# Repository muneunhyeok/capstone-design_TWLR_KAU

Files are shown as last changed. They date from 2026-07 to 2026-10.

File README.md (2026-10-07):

# TWLR — 2륜 밸런싱 로봇 (한국항공대 캡스톤디자인)

<table>
<tr>
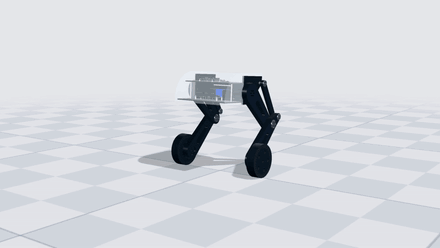
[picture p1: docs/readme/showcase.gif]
TWLR 모션 쇼케이스
<td width="50%" align="center"></td>
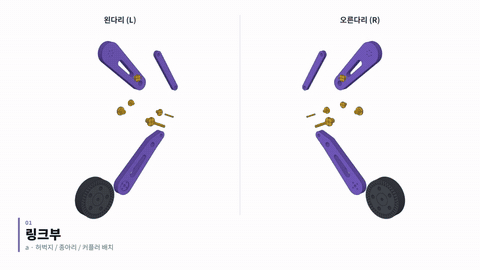
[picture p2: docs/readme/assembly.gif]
TWLR 어셈블리
<td width="50%" align="center"></td>
</tr>
<tr>
<td align="center"><b>모션 쇼케이스</b> — SQUAT · ROLL · DRIVE · TURN<br><sub>서보 축 높이 340–510 mm · 좌우 독립 롤 · 도립진자 밸런싱 주행 · 선회 시 기울기 보정</sub><br><a href="hardware/media/motion-showcase.mp4">▶ 원본 영상 (42 s)</a></td>
<td align="center"><b>어셈블리</b> — 링크부 → 토르소부 → 링크부 + 몸체<br><sub>좌우 4절 링크 다리 · 상·하판 서브어셈블리 · 커플러 부시 샤프트 체결</sub><br><a href="hardware/media/assembly-animation-v2.mp4">▶ 원본 영상 (36 s)</a></td>
</tr>
</table>

<sub>GIF 는 1.5~2 배속 미리보기입니다. 클릭하면 원본 mp4 로 이동합니다.</sub>

> **최근 변경 (2026-10)** — 고관절 액추에이터를 CubeMars AK45-36 → **Damiao DM-J4340P-2EC** 로 교체 (AK45 배송 지연).
> 토크 해석 재계산, 구매 BOM, 2·3주차 발표자료, 모션 쇼케이스·어셈블리 v2 영상 추가.

이 저장소는 두 부분으로 나뉩니다.

| | 내용 | 진입점 |
|---|---|---|
| **기구 설계 (CAD)** | CATIA, Fusion 360 어셈블리, 3D 프린팅 STL, 구조·정역학 해석 | **[`hardware/`](hardware/)** |
| **ROS 2 description** | URDF/xacro, 메시, RViz·robot_state_publisher 런치 | [`urdf/`](urdf/) · 아래 섹션 |

## 기구 설계 요약 → [`hardware/README.md`](hardware/README.md)

| | |
|---|---|
| Fusion 문서 | `TWLR_assembly_AK45` (컴포넌트 31 / 오컬런스 55 / 타임라인 281) — 고관절 인터페이스는 아직 AK45 기준 |
| 총질량 | **11.24 kg** (PLA 벽 6줄 / 인필 20 %, DM4340P 반영) |
| 무게중심 | 지면 위 **271.5 mm**, 휠축 위 **185.5 mm**, 좌우 대칭 X = 0.000 mm |
| 고관절 | Damiao **DM-J4340P-2EC** × 2 (40:1, CAN) — 직립 시 필요토크 **9.59 N·m** (정격 9 의 107 %, 피크 27 의 36 %) |
| 휠 | **WA172E** 인휠모터 Ø172 × 2 (4-M6 PCD36 체결) |
| 다리 | 좌우 **4절 링크**, 기구학 한계 Δθ = −27.1° … +36.1° · 팀 권장 운용범위 −20.9° … +21.6° (3주차) |
| 전장 | LattePanda (상위) · Teensy 4.1 (하위) · BNO085 IMU · CAN 트랜시버 · ODrive (휠) |

**영상**: [모션 쇼케이스 — SQUAT · ROLL · DRIVE · TURN](hardware/media/motion-showcase.mp4) (42 s) ·
[어셈블리 v2](hardware/media/assembly-animation-v2.mp4) (36 s) ·
[토르소 출력 시뮬레이션](hardware/media/torso-print-sim-cura.mp4) ·
[어셈블리 v1](hardware/media/assembly-animation.mp4) (27 s)

상세 문서: [01 고관절 AK45 (이전안)](docs/mechanical/01-hip-actuator-AK45.md) ·
[02 조인트/부시/샤프트](docs/mechanical/02-joints-bushings-shafts.md) ·
[03 질량·무게중심·힙토크](docs/mechanical/03-mass-cog-hip-torque.md) ·
[04 3D프린팅 방향·인필](docs/mechanical/04-print-orientation-infill.md) ·
[**05 고관절 DM4340P 변경**](docs/mechanical/05-hip-actuator-DM4340P.md) ·
[구매 BOM](hardware/bom/)

**발표자료 (2026-2학기)**

| 주차 | 발표일 | 제목 | 주요 내용 |
|---|---|---|---|
| [1주차](docs/presentations/2026-2-week1/) | 09-07 | 하드웨어 제작·설계 및 시뮬레이션 결과 보고 | Simulink, 부시·샤프트, 모터 구동 |
| [2주차](docs/presentations/2026-2-week2/) | 09-14 | 하드웨어 제작 및 시뮬레이션 결과 보고 | Simulink(CoM·피치), 모션 시뮬레이션, 부시 최소길이, 링크 3D 프린팅, 모듈 구동 |
| [3주차](docs/presentations/2026-2-week3/) | 09-21 | 하드웨어 제작 및 센서 구동 테스트 | 구동각 제한(조립·간섭·전달각), 정역학·동역학, LattePanda 휠 구동, BNO085 IMU |

---

# ROS 2 Robot Description

> ⚠️ **아래 URDF 는 구버전 Fusion 모델에서 자동생성된 것입니다.**
> 질량 63.541 kg, 링크명 `link1`/`link3` 등은 현재 CAD(`TWLR_assembly_AK45`, DM4340P 반영 11.24 kg)와 맞지 않습니다.
> 기구가 확정되었으므로 URDF 재생성이 필요합니다 — 실제 질량·관성값은
> [`hardware/analysis/results/mass-and-cog.txt`](hardware/analysis/results/mass-and-cog.txt) 참고.

## Overview (구버전 자동생성값)

| Property | Value |
|---|---|
| Total mass | 63.541 kg *(실제 11.24 kg)* |
| Links | 7 |
| Joints | 6 (6 movable) |
| Assemblies | 14 |
| Root link | `base_link` |

## Table of Contents

- [Kinematic Tree](#kinematic-tree)
- [Link Properties](#link-properties)
- [Joint Properties](#joint-properties)
- [Assembly Breakdown](#assembly-breakdown)
- [Quick Start (ROS 2)](#quick-start-ros-2)
- [Files](#files)

## Kinematic Tree

```
base_link
  └─ hip_right [continuous]
    link1_right [BAKE]
      └─ knee_right [continuous]
        link3_right [BAKE]
          └─ wheel_right [continuous]
            wheel_right [BAKE]
      └─ hip_left [continuous]
        link1_left [BAKE]
          └─ knee_left [continuous]
            link3_left [BAKE]
              └─ wheel_left [continuous]
                wheel_left [BAKE]
```

## Link Properties

| Link | Mass (kg) | Material | Collision | Bodies |
|---|---|---|---|---|
| `base_link` | 46.8047 | material | cylinder | 1 |
| `link1_left` | 0.6681 | material | box | 1 |
| `link1_right` | 0.6681 | material | box | 1 |
| `link3_left` | 0.8086 | material | cylinder | 1 |
| `link3_right` | 0.8086 | material | cylinder | 1 |
| `wheel_left` | 6.8914 | material | box | 2 |
| `wheel_right` | 6.8914 | material | box | 2 |

## Joint Properties

| Joint | Type | Parent → Child | Axis | Limits |
|---|---|---|---|---|
| `hip_left` | continuous | `link1_right` → `link1_left` | (1,0,0) | — |
| `hip_right` | continuous | `base_link` → `link1_right` | (1,0,0) | — |
| `knee_left` | continuous | `link1_left` → `link3_left` | (1,0,0) | — |
| `knee_right` | continuous | `link1_right` → `link3_right` | (1,0,0) | — |
| `wheel_left` | continuous | `link3_left` → `wheel_left` | (-0,0,-1) | — |
| `wheel_right` | continuous | `link3_right` → `wheel_right` | (0,-0,-1) | — |

## Assembly Breakdown

> 아래는 구버전 자동생성 목록이 아니라, 실제 Fusion 360 모델(`TWLR_assembly_AK45`,
> [`hardware/cad/TWLR_assembly_AK45.f3d`](hardware/cad/TWLR_assembly_AK45.f3d))에서 측정한 질량 특성입니다.
> PLA 부품은 **벽 6줄(2.4 mm) + 인필 20 %** 셸 모델 기준
> (`f = (V_shell + infill·(V−V_shell)) / V`), 구매품(DM4340P·WA172E·배터리 등)은 데이터시트/실측값.
> 고관절 액추에이터는 **DM4340P 375 g** 으로 갱신 (형상·중심은 CAD 의 AK45 자리값 사용 — 외형 Ø57 vs Ø55, 길이 동일).
> 좌표는 **고관절 축 원점** 기준 mm (X 좌우, Y 전후, Z 상하).
> 재현: [`hardware/analysis/mass_cog.py`](hardware/analysis/mass_cog.py) ·
> 원본 출력: [`hardware/analysis/results/mass-and-cog.txt`](hardware/analysis/results/mass-and-cog.txt)

### BODY — 토르소 · 배터리 · 전장 · 고관절 액추에이터 (4.615 kg)

| 부품 | 체적 [cm³] | 재료 | 유효충전율 | 질량 [g] | 중심 (X, Y, Z) mm |
|---|---:|---|---:|---:|---|
| Part12 토르소 메인 | 1486.1 | PLA | 65.4% | 1204.4 | (0.0, 47.9, −1.4) |
| Part14 외장/프레임 | 1040.8 | PLA | 88.2% | 1138.5 | (0.0, −81.4, 43.4) |
| Part13 배터리 (6S LiPo) | 301.9 | BATT | 실측 | 700.0 | (0.0, 0.0, −7.7) |
| Part16 하부 패널 | 282.3 | PLA | 100.0% | 350.0 | (0.0, −74.0, −46.2) |
| 20_ACT DM4340P L | 132.9 | DM4340P | 데이터시트 | 375.0 | (−111.9, −0.1, 0.0) |
| 20_ACT DM4340P R | 132.9 | DM4340P | 데이터시트 | 375.0 | (111.9, 0.1, 0.0) |
| Part15 상부 패널 | 260.9 | PLA | 100.0% | 323.6 | (0.0, −22.0, 46.2) |
| Driver PCB v3.5 | 34.5 | PCB | 100% | 65.5 | (−3.1, −124.8, −28.4) |
| PCB | 8.5 | PCB | 100% | 16.1 | (−0.3, −66.4, 50.3) |
| Carte PCB | 1.6 | PCB | 100% | 3.1 | (60.3, 0.2, 49.0) |

### THIGH — 허벅지 링크 · 출력 허브 · 베어링 (1.149 kg, 좌우 대칭)

| 부품 | 체적 [cm³] | 재료 | 유효충전율 | 질량 [g] | 중심 (X, Y, Z) mm |
|---|---:|---|---:|---:|---|
| 06_Thigh_L | 604.8 | PLA | 45.7% | 342.5 | (−187.1, 73.6, −69.3) |
| 08_Thigh_R | 604.8 | PLA | 45.7% | 342.5 | (187.1, 73.6, −69.3) |
| 21_HUB L (출력 허브) | 49.1 | AL6061 | 100% | 132.4 | (−162.8, 0.0, 0.0) |
| 21_HUB R | 49.1 | AL6061 | 100% | 132.4 | (162.8, 0.0, 0.0) |
| 6905 베어링 ×4 (25×42×9) | 6.3 ea | STEEL | 100% | 49.8 ea | X = ∓177.5 / ∓186.5 |

### SHIN — 종아리 링크 · 인휠모터 · 베어링/부시 (5.300 kg, 좌우 대칭)

| 부품 | 체적 [cm³] | 재료 | 유효충전율 | 질량 [g] | 중심 (X, Y, Z) mm |
|---|---:|---|---:|---:|---|
| 10_Wheel_WA172E_L | 947.4 | WA172E | 실측 | 2200.0 | (−257.6, 4.0, −336.0) |
| 11_Wheel_WA172E_R | 947.4 | WA172E | 실측 | 2200.0 | (257.6, 4.0, −336.0) |
| 07_Shin_L | 577.9 | PLA | 50.8% | 364.4 | (−213.9, 106.7, −234.9) |
| 09_Shin_R | 577.9 | PLA | 50.8% | 364.4 | (213.9, 106.7, −234.9) |
| 6904 베어링 ×4 (20×37×9) | 5.4 ea | STEEL | 100% | 42.3 ea | X = ∓215.5 / ∓224.5, (Y,Z)=(174.0,−164.0) |
| bush @B (플랜지 부시) ×2 | 0.8 ea | iglidur | 100% | 1.2 ea | X = ∓165.0, (Y,Z)=(228.5,−128.6) |

### COUP — 보조링크 · 부시 (0.176 kg, 좌우 대칭)

| 부품 | 체적 [cm³] | 재료 | 유효충전율 | 질량 [g] | 중심 (X, Y, Z) mm |
|---|---:|---|---:|---:|---|
| 02_Coupler_L | 116.2 | PLA | 60.2% | 86.7 | (−162.0, 169.3, −36.7) |
| 03_Coupler_R | 116.2 | PLA | 60.2% | 86.7 | (162.0, 169.3, −36.7) |
| bush @A (플랜지 부시) ×2 | 0.8 ea | iglidur | 100% | 1.2 ea | X = ∓165.0, (Y,Z)=(114.0,49.0) |

### 전체 합계

| 항목 | 값 |
|---|---|
| 그룹 BODY | 4.615 kg |
| 그룹 THIGH | 1.149 kg |
| 그룹 SHIN | 5.300 kg |
| 그룹 COUP | 0.176 kg |
| **총질량** | **11.239 kg** (AK45 기준 11.187 kg) |
| **무게중심** | **(−0.0, 11.4, −150.5) mm** — 고관절 축 원점 기준 |
| 지면(휠 반경 86 mm) 기준 CoG 높이 | **271.5 mm** |

## Quick Start (ROS 2)

```bash
# 1. Copy package to your ROS 2 workspace
cp -r TWLR_description ~/ros2_ws/src/

# 2. Build
cd ~/ros2_ws
colcon build --packages-select TWLR_description
source install/setup.bash

# 3. Visualize in RViz2
ros2 launch TWLR_description display.launch.py

# 4. Validate URDF structure
check_urdf install/TWLR_description/share/TWLR_description/urdf/TWLR.urdf

# 5. Print kinematic tree
urdf_to_graphviz install/TWLR_description/share/TWLR_description/urdf/TWLR.urdf
```

**Joint control**: The launch file includes `joint_state_publisher_gui` —
use the sliders to move revolute/prismatic joints in RViz2.

**Topic inspection**:
```bash
# See published joint states
ros2 topic echo /joint_states

# See robot description parameter
ros2 param get /robot_state_publisher robot_description
```

## Files

| Path | Description |
|---|---|
| `urdf/TWLR.urdf.xacro` | Top-level xacro (entry point) |
| `urdf/TWLR.urdf` | Flat URDF (for validation) |
| `urdf/assemblies/` | Per-assembly xacro macros |
| `meshes/` | Visual (OBJ) and collision (STL) meshes |
| `launch/display.launch.py` | Launch robot_state_publisher, RViz, and generated controllers |
| `config/joint_state.yaml` | Joint state publisher config |
| `config/ros2_controllers.yaml` | Generated ros2_control controller manager config |
| `robot_data.yaml` | Supplementary data (beyond URDF) |
| `docs/transforms.md` | Transformation matrices (KaTeX) |
| `hardware/` | **기구 설계 — CAD, STL, 해석 (아래 표)** |
| `hardware/cad/TWLR_assembly_AK45.f3d` | Fusion 360 어셈블리 원본 |
| `hardware/cad/step/` | 신규 가공품 STEP (허브·마운트링·샤프트 3종) |
| `hardware/print/print-ready/` | 슬라이서용 STL — 구멍 없음 + 눕힘 + 베드 최적 회전 |
| `hardware/print/as-designed/` | 설계 그대로의 STL (구멍 포함) |
| `hardware/analysis/` | 질량·힙토크·볼트·프린팅 강도 해석 스크립트 + 결과 |
| `hardware/media/` | 어셈블리 애니메이션 v1·v2, 모션 쇼케이스, 토르소 출력 시뮬레이션 |
| `hardware/bom/` | 구매 BOM (xlsx + 요약) |
| `docs/mechanical/` | 기구 설계 상세 문서 5편 (05 = DM4340P 변경) |
| `firmware/` | Teensy 4.1 펌웨어 (BNO085 쿼터니언 송신) |
| `host/` | LattePanda/Ubuntu 측 코드 (IMU 수신·파싱, ODrive 휠 설정) |
| `docs/presentations/2026-2-week{1,2,3}/` | 2026-2학기 주차별 발표자료 (슬라이드·PDF·영상) |

## Customizing

Assemblies tagged `!dummy_` are designed to be swapped out. To replace one:

1. Create your replacement as a xacro macro with the same interface
2. Place it in `urdf/assemblies/`
3. Update the `<xacro:include>` in `urdf/TWLR.urdf.xacro`
4. Update meshes in `meshes/<your_assembly>/`

The xacro prefix system (`${prefix}`) ensures link names stay unique
when multiple instances of the same assembly are used.

---
*Generated by Fusion URDF/XACRO Exporter v3.0.0*

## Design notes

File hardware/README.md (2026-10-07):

# TWLR — 기구 설계 (Mechanical Design)

한국항공대학교 기계공학과 캡스톤디자인 · 2륜 밸런싱 로봇 **TWLR**

Fusion 360 문서: **`TWLR_assembly_AK45`** — 컴포넌트 31, 오컬런스 55, 타임라인 281, 스냅샷 7

> **2026-10 고관절 액추에이터 변경**: CubeMars AK45-36 → **Damiao DM-J4340P-2EC** (AK45 배송 지연).
> 해석값은 DM4340P 기준으로 갱신했고, CAD 의 허브/마운트링은 아직 AK45 기준입니다 → [05](../docs/mechanical/05-hip-actuator-DM4340P.md)

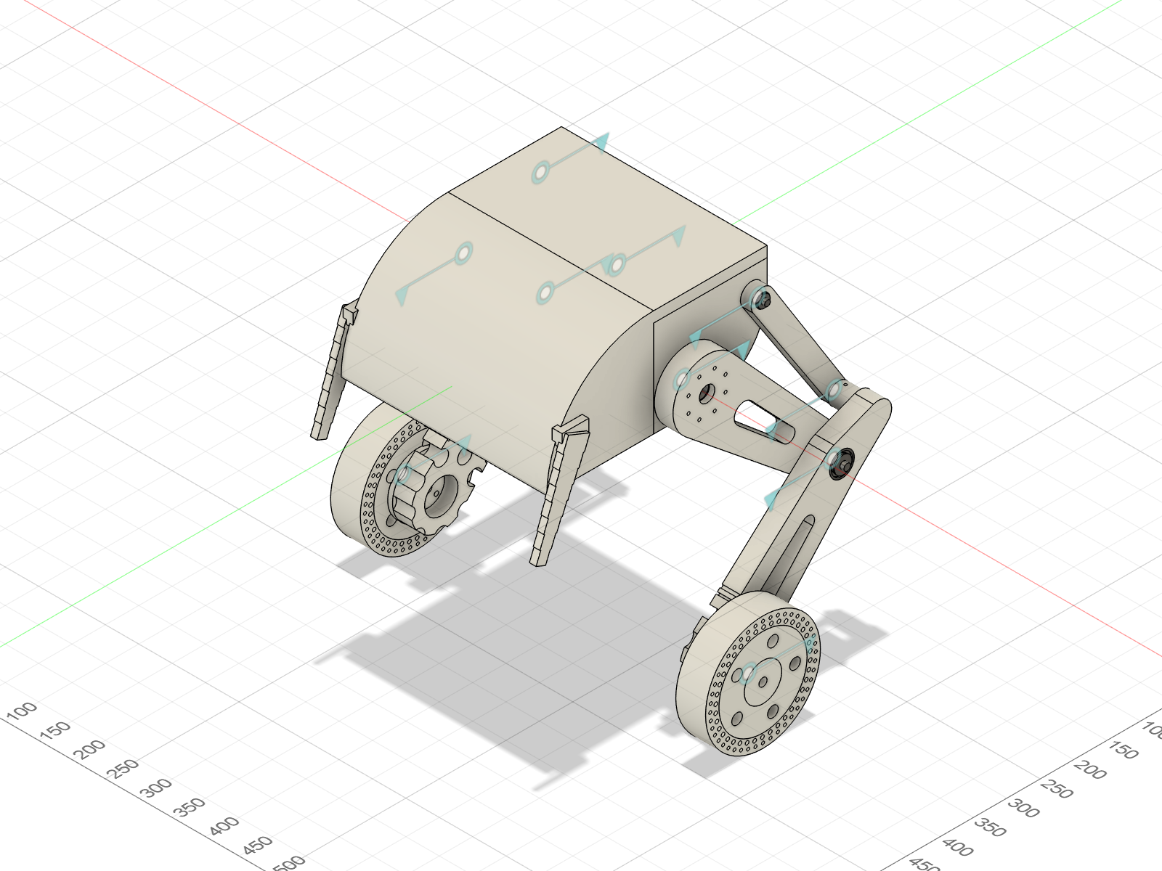
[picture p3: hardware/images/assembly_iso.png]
TWLR assembly


▶ **어셈블리 애니메이션 v2** (링크부 → 토르소부 → 결합, 36 s): [`media/assembly-animation-v2.mp4`](media/assembly-animation-v2.mp4)
· **모션 쇼케이스** (SQUAT · ROLL · DRIVE · TURN, 42 s): [`media/motion-showcase.mp4`](media/motion-showcase.mp4)
· 토르소 출력 시뮬레이션 (Cura): [`media/torso-print-sim-cura.mp4`](media/torso-print-sim-cura.mp4)
· v1 (27 s): [`media/assembly-animation.mp4`](media/assembly-animation.mp4)

발표자료: [1주차](../docs/presentations/2026-2-week1/) · [2주차](../docs/presentations/2026-2-week2/) · [3주차](../docs/presentations/2026-2-week3/)
· 구매 BOM: [`bom/`](bom/)

| | |
|---|---|
| 총질량 | **11.24 kg** (PLA 벽 6줄 / 인필 20 % 기준, DM4340P 반영) |
| 무게중심 | (0.0, +11.4, −150.5) mm — 지면에서 **271.5 mm**, 휠축 위 **185.5 mm** |
| 고관절 액추에이터 | Damiao **DM-J4340P-2EC** × 2 (40:1, 정격 9 N·m / 피크 27 N·m, CAN, 듀얼 엔코더) |
| 구동 휠 | **WA172E** 인휠모터 Ø172 × 2 |
| 다리 구조 | 좌우 **4절 링크** (허벅지 + 종아리 + 보조링크) |
| 좌우 대칭 | 무게중심 X = 0.000 mm |

<table>
<tr>
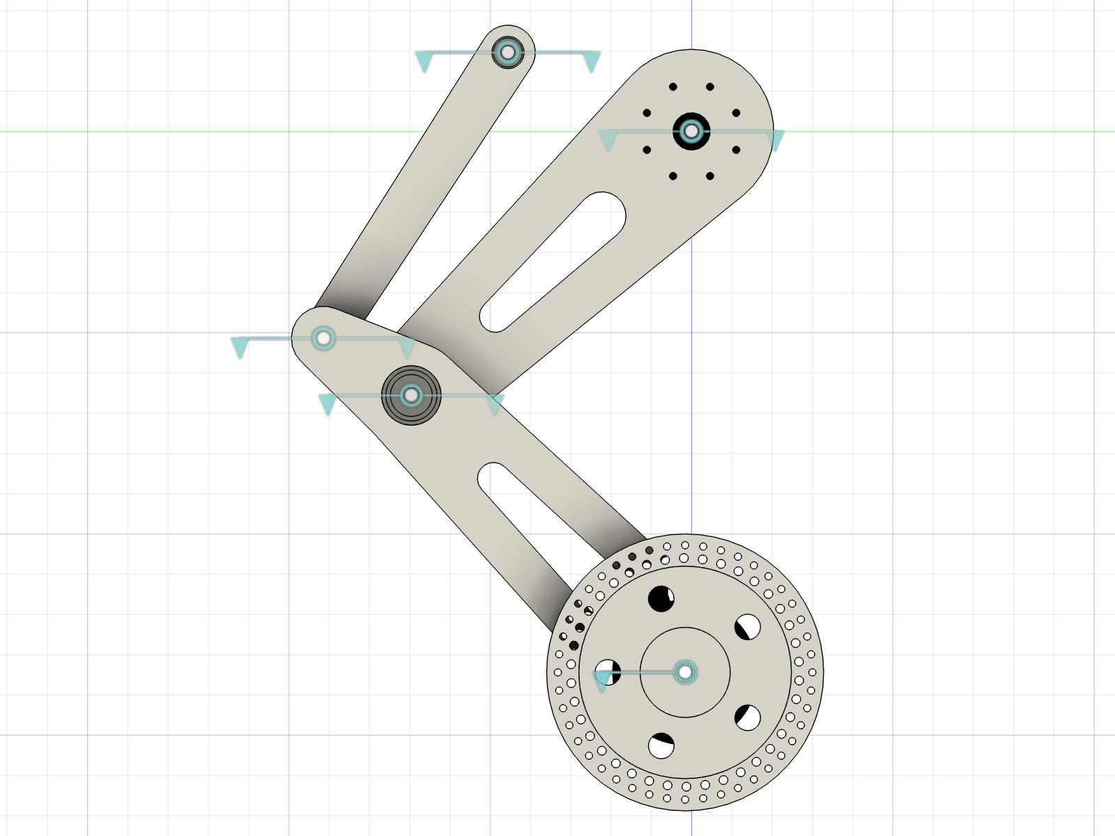
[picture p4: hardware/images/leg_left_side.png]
left leg
<td width="50%"></td>
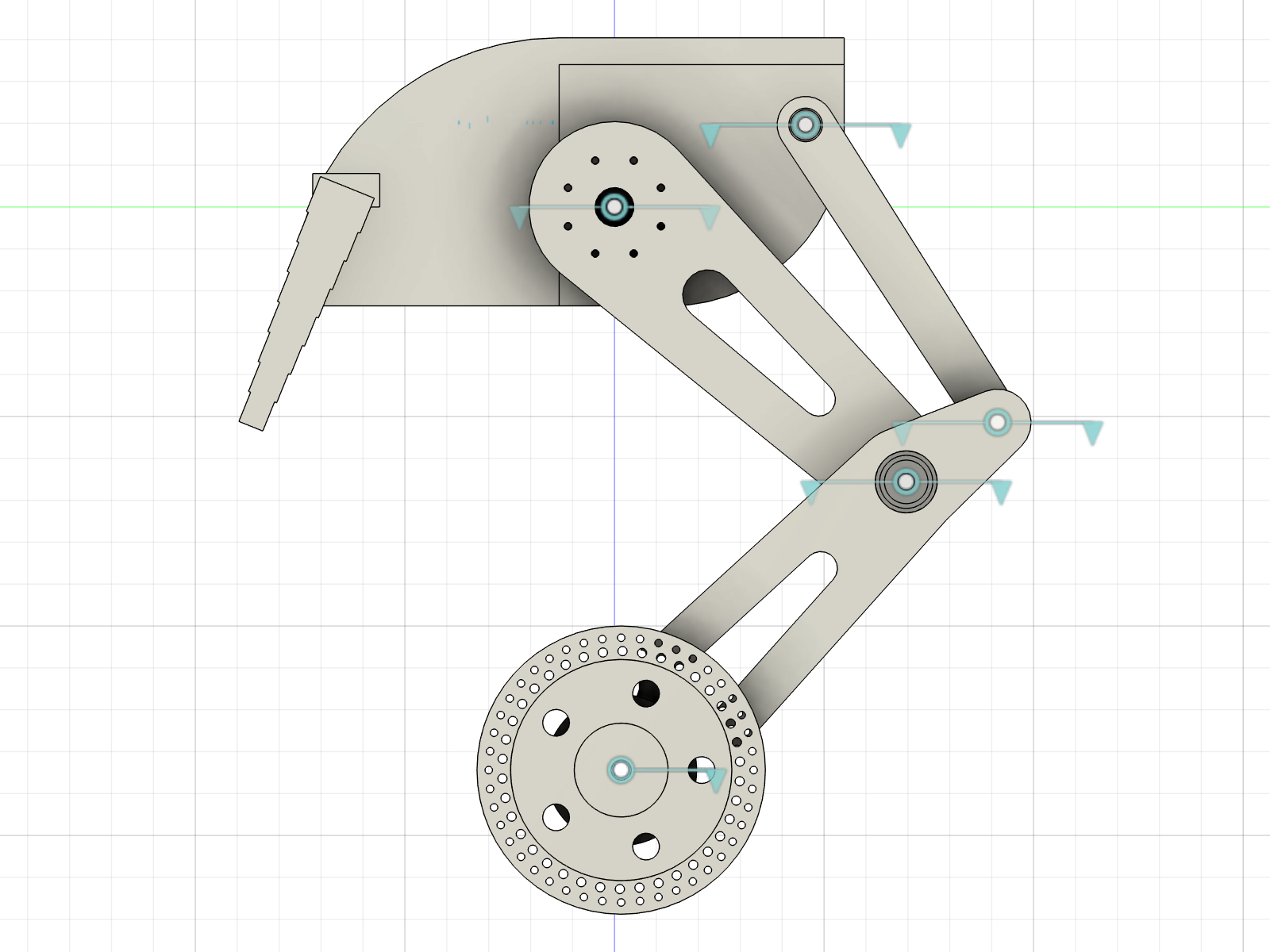
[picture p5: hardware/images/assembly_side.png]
side view
<td width="50%"></td>
</tr>
<tr><td align="center">좌측 다리 4절 링크</td><td align="center">측면</td></tr>
</table>

---

## 1. 좌표계

어셈블리 원점 = **좌우 고관절 축의 중점**

| 축 | 방향 |
|---|---|
| **X** | 좌우 (우측 +) |
| **Y** | 전후 |
| **Z** | 상하 (위 +) |

지면은 Z = −336 − 86 = **−422 mm** (휠 중심 Z = −336, 휠 반경 86).

## 2. 링크 구조 (4절 링크)

```
        고관절 (0, 0)                     A (114, 49)
             │  L1 = 239.1                     │
             │                                 │ L3 = 211.3
        무릎 (174, −164) ──── L2 = 65.0 ──── B (228.5, −128.6)
             │
             │ 241.8
        휠축 (4, −336)   ← Ø172 인휠모터
```

| 조인트 | 위치 (Y, Z) mm | 연결 | 베어링 / 부시 |
|---|---|---|---|
| **HIP** | (0, 0) | 토르소 ↔ 허벅지 | DM4340P 내장 크로스 롤러 베어링 |
| **A** | (114, 49) | 토르소 ↔ 보조링크 | 플랜지 부시 Ø12/Ø14 L15 |
| **KNEE** | (174, −164) | 허벅지 ↔ 종아리 | 6904ZZ × 2 |
| **B** | (228.5, −128.6) | 보조링크 ↔ 종아리 | 플랜지 부시 Ø12/Ø14 L15 |
| **WHEEL** | (4, −336) | 종아리 ↔ 휠 | 인휠모터 내장 |

고관절 각도 가동범위 Δθ = **−27.1° … +36.1°** (Grashof 조건 및 4절 폐쇄해 기준)

## 3. 부품 목록 (BOM)

### 3-1. 3D 프린팅 (PLA)

| 부품 | 수량 | 체적 | 외형 (T×Y×Z) |
|---|---|---|---|
| `06_Thigh_L` / `08_Thigh_R` 허벅지 | 2 | 604,281 mm³ | 28 × 258 × 248 |
| `07_Shin_L` / `09_Shin_R` 종아리 | 2 | 571,740 mm³ | 65 × 288.5 × 271.4 |
| `02_Coupler_L` / `03_Coupler_R` 보조링크 | 2 | 116,188 mm³ | 16 × 146.5 × 209.6 |
| `Part12` 토르소 메인 | 1 | 1,486,107 mm³ | 308 × 170 × 144 |
| `Part14` 외장 / `Part15` 상판 / `Part16` 하판 | 각 1 | 1,040,771 / 260,945 / 282,257 mm³ | — |

### 3-2. 신규 가공품 (알루미늄 / 강)

| 부품 | 수량 | 체적 | 재질 권고 | 기능 |
|---|---|---|---|---|
| `21_HUB_Hip_Output` | 2 | 49,052 mm³ | **A6061-T6** | 액추에이터 출력 → 허벅지(Ø70/PCD60) 어댑터 — **DM4340P 출력 플랜지에 맞춰 재설계 필요** |
| `22_MNT_AK45_Ring` | 2 | 11,738 mm³ | A6061-T6 | 액추에이터 하우징 ↔ 토르소 끝판 — **DM4340P 하우징 패턴에 맞춰 재설계 필요** |
| `40_SHAFT_A_D17-D12_L27` | 2 | 3,915 mm³ | S45C/SUS304 연마 | A 조인트 단차 샤프트, 양단 M5 탭 |
| `41_SHAFT_KNEE_D20_L56` | 2 | 17,122 mm³ | S45C 연마 (h7) | 무릎 샤프트, 양단 M6 탭 |
| `42_SHAFT_B_D12_L37` | 2 | 4,046 mm³ | S45C 연마 (g6) | B 조인트 샤프트, 편단 M5 탭 |

### 3-3. 구매품

| 품목 | 수량 | 비고 |
|---|---|---|
| **Damiao DM-J4340P-2EC** (24 V) | 2 | 375 g, Ø57 × 56.5, 정격 3.0 A / 피크 8 A — *AK45-36(349 g) 대체* |
| WA172E 인휠모터 Ø172 (BOM 품명: 누리로봇 인휠모터) | 2 | 2,200 g, 4-M6 × 5DP PCD36 + Ø50 스피곳 |
| 6904ZZ (20×37×9) | 4 | 무릎 |
| 6905 (25×42×9) | 4 | **현재 무기능** — 제거 시 199 g 절감 (§6) |
| 플랜지 부시 Ø12/Ø14 L15 | 4 | DU 부시 권장 ([상세](../docs/mechanical/02-joints-bushings-shafts.md)) |
| M5 + Ø18 와셔 / M5 + Ø30 / M6 + Ø26 / M6 + Ø30 | 4 / 2 / 2 / 2 | 샤프트 축방향 고정 |
| M4 세트스크루 × 8 | 4 | 샤프트 회전방지 |
| 황동 열간삽입 인서트 M4 | 12 | **PLA 직접탭 금지** (안전율 0.47) |
| 6S LiPo (VEGA 그래핀 22.2 V 5200 mAh) | 1 | 700 g |

전체 구매 목록·가격(총 1,184,795원): [`bom/README.md`](bom/README.md)

## 4. 체결 사양 (편차 전부 0.000 mm 검증 — 고관절 2행은 AK45 기준)

| 체결부 | 규격 | 비고 |
|---|---|---|
| 링 ↔ AK45 하우징 | 6 × M3, PCD48 | M3×8 |
| 링 ↔ 토르소 끝판 | 6 × M4, PCD60 | M4×12, 인서트 필수 |
| 허브 ↔ AK45 출력 | 6 × M3, PCD27 + Ø18h7 스피곳 + **3 × Ø4 다웰** | 다웰 없으면 안전율 1.10 → 미끄러짐 |
| 허브 ↔ 허벅지 | 8 × M4, PCD60 | M4×35, 허브에 탭 |
| 종아리 ↔ WA172E | 4 × M6, PCD36 + Ø49.95 스피곳 | **Ø18 대형와셔 + 조임 4~6 N·m 제한** |

## 4-1. 전장 구성 (2·3주차 진행)

| 계층 | 부품 | 역할 / 확인 상태 |
|---|---|---|
| 상위 제어기 | **LattePanda** (4 GB / 64 GB, Win10 Ent.) | 상태 모니터링·데이터 처리, Teensy 에 목표 자세·속도 전달 — 부팅·환경 테스트 완료 |
| 하위 제어기 | **Teensy 4.1** | IMU 수신, 액추에이터 지령 — USB 시리얼로 상위와 연결 |
| 자세 센서 | **BNO085** IMU (I²C) | Game Rotation Vector 쿼터니언 → Roll/Pitch/Yaw 변환 출력 확인 |
| 고관절 | DM4340P × 2 | CAN 1 Mbps (CAN 트랜시버 경유) |
| 휠 | WA172E × 2 + ODrive | LattePanda 에서 ODrive 설정·속도 제어 구동 확인 (pole_pairs 15, cpr 3200) |
| 전원 | 6S 22.2 V + 24 → 5 V 강압 | XT90 |

코드·영상: [3주차 발표](../docs/presentations/2026-2-week3/)

## 5. 해석 요약

| 항목 | 결과 | 상세 |
|---|---|---|
| 총질량 / 무게중심 | 11.24 kg / 지면 위 271.5 mm | [03](../docs/mechanical/03-mass-cog-hip-torque.md) |
| 고관절 필요토크 | **9.59 N·m** @Δθ=0 (DM4340P 정격 9 N·m의 107 %, 피크 27 N·m의 36 %) | [05](../docs/mechanical/05-hip-actuator-DM4340P.md) |
| 연속운전 가능 구간 | Δθ ≤ −5.5° (정격 9 N·m) · 피크 27 N·m 도달 Δθ = +31.8° | [05](../docs/mechanical/05-hip-actuator-DM4340P.md) |
| 팀 권장 운용범위 접힘 끝 (Δθ = +21.6°) | 14.50 N·m (정격 161 %, 피크 54 %) — 팀 정역학 8.5 N·m 와 질량 가정 차이 확인 필요 | [05 §3](../docs/mechanical/05-hip-actuator-DM4340P.md) |
| 링크 굽힘 (3G 착지) | 눕혀 출력 시 SF 1.65 / 세워 출력 시 1.21 | [04](../docs/mechanical/04-print-orientation-infill.md) |
| 고관절 캔틸레버 | 정지 6.54 / 3G 19.61 N·m vs 베어링 ≈27.6 N·m | [02](../docs/mechanical/02-joints-bushings-shafts.md) |
| 간섭 해석 (55 오컬런스) | 실질 간섭 **0건** | [01](../docs/mechanical/01-hip-actuator-AK45.md) |

## 6. 미해결 / 판단 필요

1. **6905 베어링 4개 무기능** — 허브가 허벅지에 직결이라 내륜에 들어갈 축이 없음. 제거 시 199 g 절감.
2. **고관절 모멘트 지지 보강** — 허브 Ø36 축이 AK45 출력 베어링에서 22 mm 캔틸레버. 허브 축을 Ø35로 낮추고 토르소 보어를 Ø47로 넓혀 6807(35×47×7) 삽입하면 해소. 토르소 가공 필요로 미반영.
3. **CAD 의 액추에이터는 AK45 플레이스홀더** — DM4340P 설치도면으로 `21_HUB`·`22_MNT` 재설계, 토르소 격벽 관통 Ø56 → Ø58 이상.
4. **토르소 질량 확인** — 팀 정역학은 토르소 3 kg 가정, CAD 모델은 BODY 4.6 kg. 실측 후 한쪽으로 통일.
5. **백래시** — AK45 기준 ±1.17 mm(휠 위치). DM4340P 백래시는 사양 미공개 → 실측 필요.
6. **URDF의 질량값(63.5 kg)은 구버전 자동생성분** — 실제 11.24 kg. `urdf/` 재생성 필요.

## 7. 디렉터리

```
hardware/
├── cad/
│   ├── TWLR_assembly_AK45.f3d      Fusion 360 원본 (6.9 MB)
│   └── step/                        신규 가공품 STEP 5종
├── print/
│   ├── print-ready/  *_PRINT.stl    구멍 없음 + 눕힘 + 베드 최적 회전 + Z=0
│   ├── as-designed/  *.stl          설계 그대로 (구멍 포함)
│   └── README.md                    슬라이서 설정
├── analysis/         재현 가능한 파이썬 해석 스크립트 + 결과 (DM4340P 기본, AK45 재현 가능)
├── bom/              구매 BOM (xlsx + 요약)
├── media/            어셈블리 애니메이션 v1·v2, 모션 쇼케이스, 토르소 출력 시뮬레이션
└── images/
```

관련 문서: [`docs/mechanical/`](../docs/mechanical/)

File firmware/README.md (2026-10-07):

# Teensy 4.1 펌웨어

| 폴더 | 내용 |
|---|---|
| [`teensy_bno085_quat/`](teensy_bno085_quat/) | BNO085 IMU(I²C) 의 Game Rotation Vector 를 읽어 쿼터니언 `i,j,k,real` 을 USB 시리얼 115200 으로 CSV 출력. Arduino IDE + Teensyduino, 라이브러리 `Adafruit BNO08x` |

호스트 수신 코드: [`../host/imu_serial_reader.py`](../host/imu_serial_reader.py)

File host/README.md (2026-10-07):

# 호스트 측 코드 (LattePanda / Ubuntu)

| 파일 | 내용 | 출처 |
|---|---|---|
| [`imu_serial_reader.py`](imu_serial_reader.py) | Teensy 4.1 이 보내는 BNO085 쿼터니언 CSV(`i,j,k,real`) 수신·파싱 | 3주차 발표 슬라이드 22 |
| [`odrive_wheel_config.odrivetool.py`](odrive_wheel_config.odrivetool.py) | 휠모터 ODrive 설정 (pole_pairs 15, 인크리멘털 엔코더 cpr 3200, 시작 게인) — `odrivetool` 셸에 붙여넣기 | 3주차 발표 슬라이드 19 |

Teensy 펌웨어: [`../firmware/teensy_bno085_quat/`](../firmware/teensy_bno085_quat/)

```
BNO085 ──I²C──▶ Teensy 4.1 ──USB 시리얼 115200──▶ LattePanda (imu_serial_reader.py)
                    │
                    └──CAN 1 Mbps (트랜시버)──▶ DM4340P × 2   (계획)
LattePanda ──USB──▶ ODrive ──▶ WA172E 휠 × 2
```

다음 단계: 쿼터니언 → Roll/Pitch/Yaw 변환 후 ROS 2 토픽(`sensor_msgs/Imu`)으로 발행, 밸런싱 제어 입력으로 연결.

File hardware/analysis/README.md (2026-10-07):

# 해석 스크립트

전부 순수 파이썬(표준 라이브러리)으로 돌아갑니다. 입력값은 Fusion 모델 실측치가 스크립트 안에 하드코딩되어 있습니다.

| 스크립트 | 내용 |
|---|---|
| `mass_cog.py` | 부품별 질량 → 총질량 / 무게중심. PLA는 셸+인필 모델 (`INFILL`, `WALL_T` 상수). `parts.json` 출력 |
| `hip_torque3.py` | 4절 링크 폐쇄해 + 가상일 원리로 고관절 필요토크 τ(Δθ). `mass_cog.py` 를 먼저 실행해야 함 |
| `sweep_infill.py` | 인필/벽 두께를 바꿔가며 질량·무게중심·고관절 토크 변화를 표로 |
| `print_strength.py` | 적층 방향 × 인필 → 굽힘 안전율. 단면은 Fusion에서 0.5 mm 격자로 수치적분한 실제 단면 |
| `bolt_check.py` | 볼트 마찰 전달 여유, PLA 면압, 열간삽입 인서트 비교 |

```bash
python3 mass_cog.py        # → parts.json   (고관절 기본 = DM4340P)
python3 hip_torque3.py
python3 sweep_infill.py    # parts.json 을 마지막 조합으로 덮어쓰므로 마지막에 실행
python3 print_strength.py
python3 bolt_check.py      # ※ 아직 AK45 플랜지(피크 24 N·m) 기준

# 이전안(AK45-36) 재현
TWLR_ACT=AK45 python3 mass_cog.py && TWLR_ACT=AK45 python3 hip_torque3.py
```

고관절 액추에이터 사양은 `mass_cog.py` / `hip_torque3.py` 상단 `ACTUATORS` 표에 있습니다.

| 키 | 모델 | 질량 | 정격 / 피크 |
|---|---|---|---|
| `DM4340P` (기본) | Damiao DM-J4340P-2EC 24 V, 40:1 | 375 g | 9 / 27 N·m |
| `AK45` | CubeMars AK45-36 V3.0 KV80 | 349 g | 8 / 24 N·m |

결과 스냅샷: [`results/`](results/) — 접미사 없는 파일이 DM4340P, `*_AK45.txt` 가 이전안

## 해석 가정

| 항목 | 값 |
|---|---|
| PLA 밀도 | 1.24 g/cm³ |
| 셸 모델 | `f = (V_shell + infill·(V − V_shell)) / V`, `V_shell = min(A·t_wall, V)` |
| PLA 설계허용응력 | 층내(눕힘) 17 MPa · 층간(세움) 7 MPa (UTS 50 / 28 MPa 에 안전계수 3 / 4) |
| 응력집중 Kt | 1.8 |
| 볼트 | 토크계수 K = 0.20, 마찰계수 μ = 0.15 |
| 하중 케이스 | A 정지 / B 급가감속 1G (μ=0.8 + 휠토크 반력) / C 3G 착지 |

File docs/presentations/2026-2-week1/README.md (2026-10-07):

# 2026-2학기 1주차 발표 — 하드웨어 제작·설계 및 시뮬레이션 결과 보고

2조 · 발표일 2026-09-07 · 슬라이드 12장 · 다음: [2주차](../2026-2-week2/) · [3주차](../2026-2-week3/)

- 전체 슬라이드 PDF: [`2026-2-week1.pdf`](2026-2-week1.pdf)
- 원본 `.pptx` (101 MB) 는 GitHub 파일 크기 제한 때문에 커밋하지 않고, **슬라이드 이미지 + 영상 + PDF** 로 분해해 넣었습니다.
- 영상은 전부 H.264 로 재인코딩했습니다 (원본 .mov 는 HEVC 라 브라우저에서 재생 안 됨).

## 목차

| # | 섹션 | 내용 |
|---|---|---|
| 01 | MATLAB Simulink | 스쿼트 모션 / 주행 / 주행+스쿼트 영상 및 피치 스코프 |
| 02 | 링크부 체결 | MISUMI 부시·샤프트 결합, 링크별 부시 최소길이 |
| 03 | Hardware Design & Assembly | Supporter 설계, Assembly Video |
| 04 | 모터 구동영상 | 서보모터 / 인휠모터 |
| 05 | 하드웨어 제작 계획 | 3D printing (교내 드론앵커센터 / 기계공작실) |

---

## 01 — MATLAB Simulink

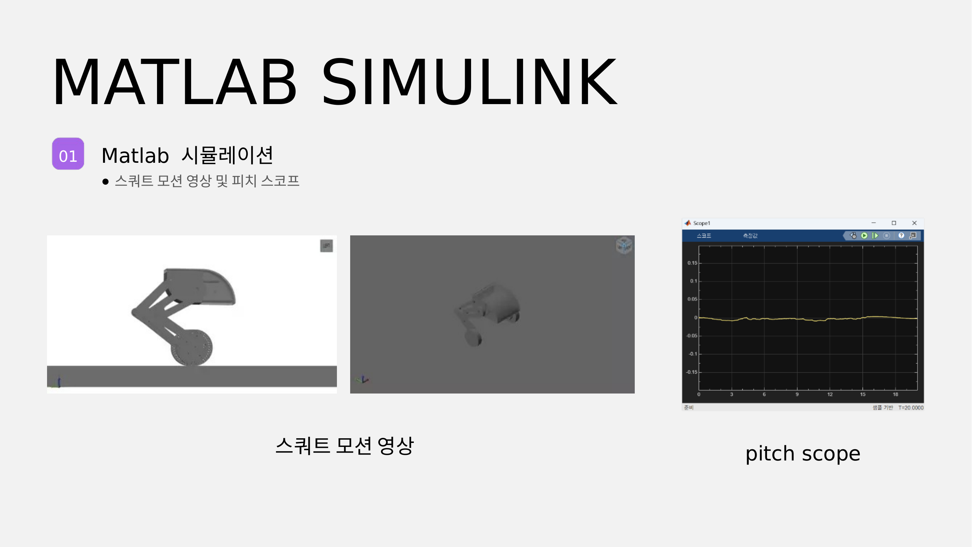
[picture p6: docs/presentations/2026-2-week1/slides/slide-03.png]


**스쿼트 모션** — [측면 뷰](video/sim-squat-side.mp4) · [등각 뷰](video/sim-squat-iso.mp4)

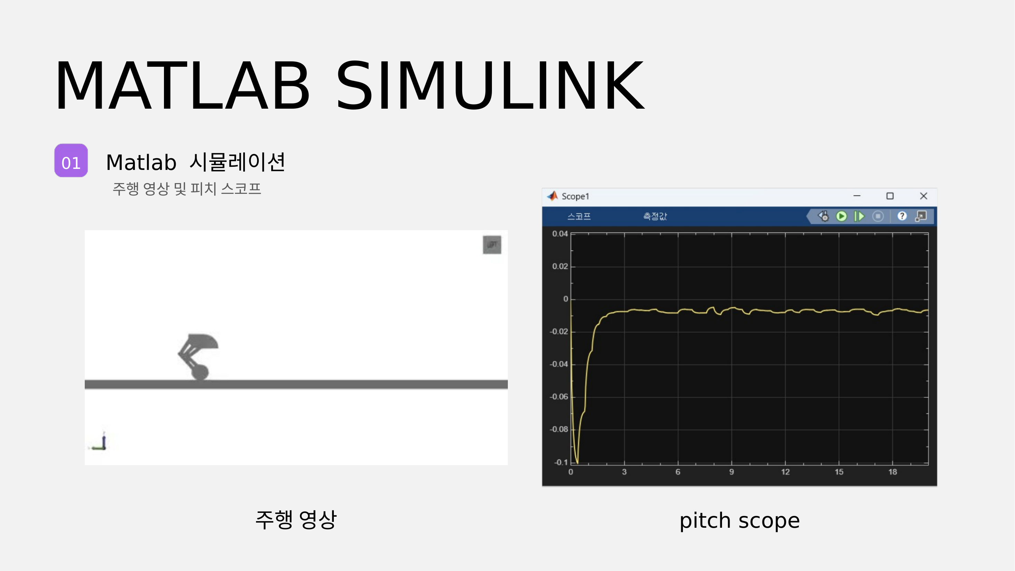
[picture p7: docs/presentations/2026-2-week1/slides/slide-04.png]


**주행** — [영상](video/sim-drive.mp4)

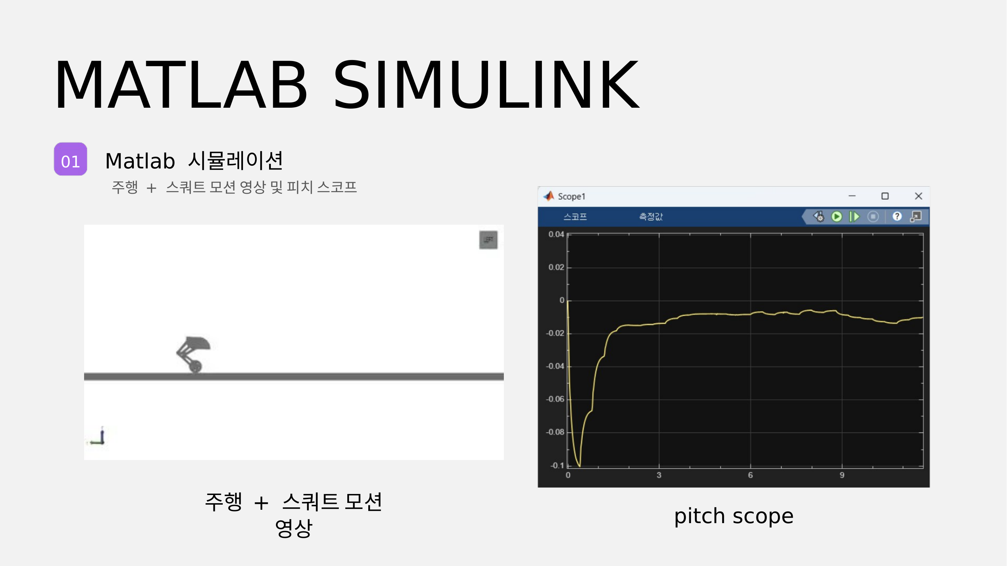
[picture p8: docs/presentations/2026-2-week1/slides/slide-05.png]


**주행 + 스쿼트** — [영상](video/sim-drive-squat.mp4)

---

## 02 — 링크부 체결

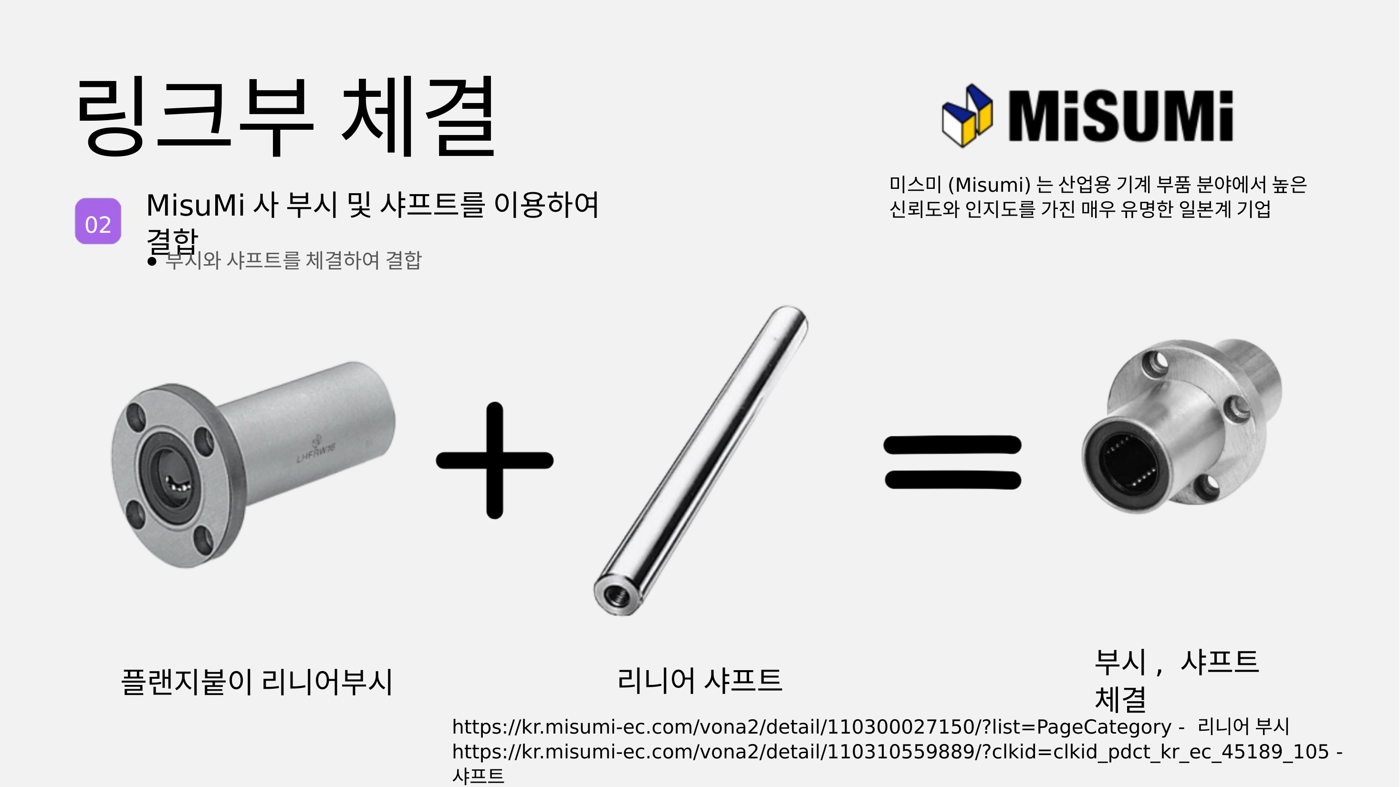
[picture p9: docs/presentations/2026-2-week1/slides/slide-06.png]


> ⚠️ **발표 후 정정**: 이 슬라이드에 링크된
> [MISUMI 110300027150 플랜지붙이 리니어부시](https://kr.misumi-ec.com/vona2/detail/110300027150/) 는
> **볼 리니어부시(LM 부시)로 직선 왕복 전용**입니다. 회전시키면 볼이 궤도를 압흔(brinelling)시켜
> 수 시간 만에 유격이 생깁니다. TWLR 의 A·KNEE·B 조인트는 전부 요동 회전이므로 사용 불가.
> → **오일리스 부시(MPFZ) / OILES GSF / DU 부시**로 대체.
> 샤프트도 **양단 암나사 타입(SFJ/PSFJ)** 을 골라야 합니다.
> 상세: [`../../mechanical/02-joints-bushings-shafts.md`](../../mechanical/02-joints-bushings-shafts.md#3-misumi-부품--️-선택하신-품번은-회전에-쓰면-안-됩니다)

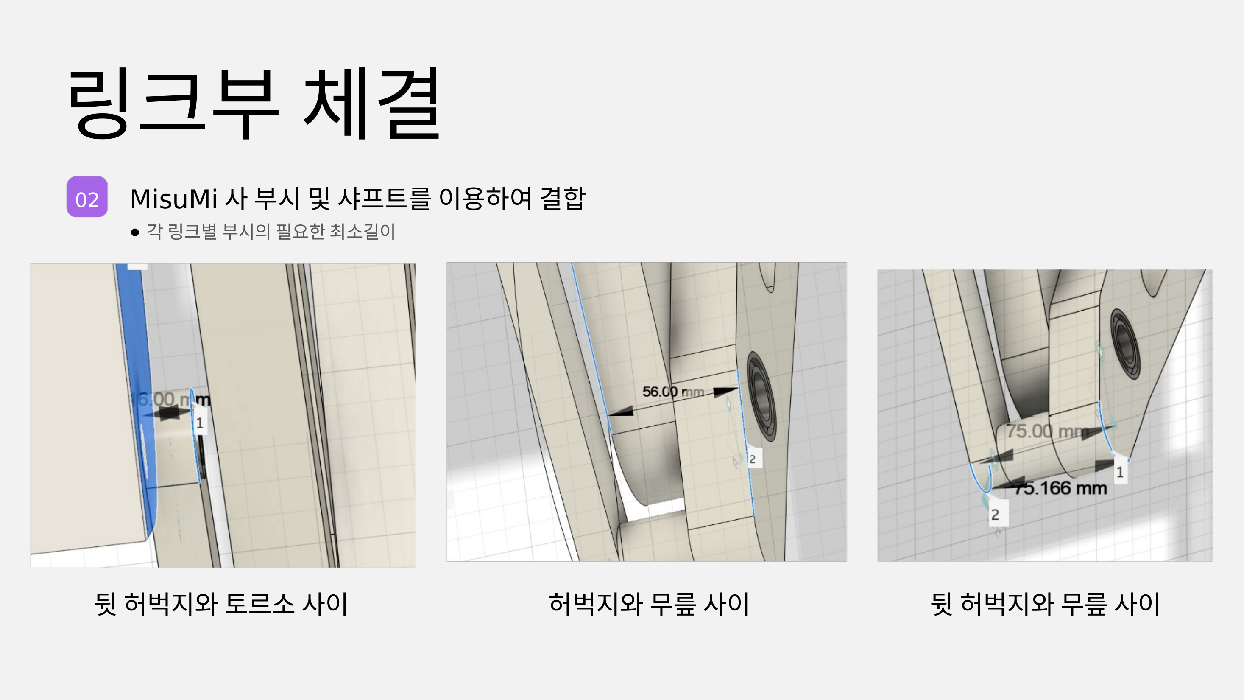
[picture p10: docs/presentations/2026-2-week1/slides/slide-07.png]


**부시 최소길이** — 계산 결과 면압은 전혀 제약이 아니고(필요 L ≈ 1.0 mm),
길이는 **미스얼라인 방지 기준 L/d ≥ 1.0** 으로 잡아야 합니다. 현재 L15/Ø12 = 1.25 ✓

| 조인트 | 위치 (Y, Z) | 하중(3G) | 축경 | 필요 L | 현재 |
|---|---|---|---|---|---|
| A (토르소 ↔ 보조링크) | (114, 49) | ≈250 N | Ø12 | 1.0 mm | L15 ✓ |
| KNEE (허벅지 ↔ 종아리) | (174, −164) | ≈560 N | Ø20 | 6904ZZ ×2 | ✓ |
| B (보조링크 ↔ 종아리) | (228.5, −128.6) | ≈250 N | Ø12 | 1.0 mm | L15 ✓ |

---

## 03 — Hardware Design & Assembly

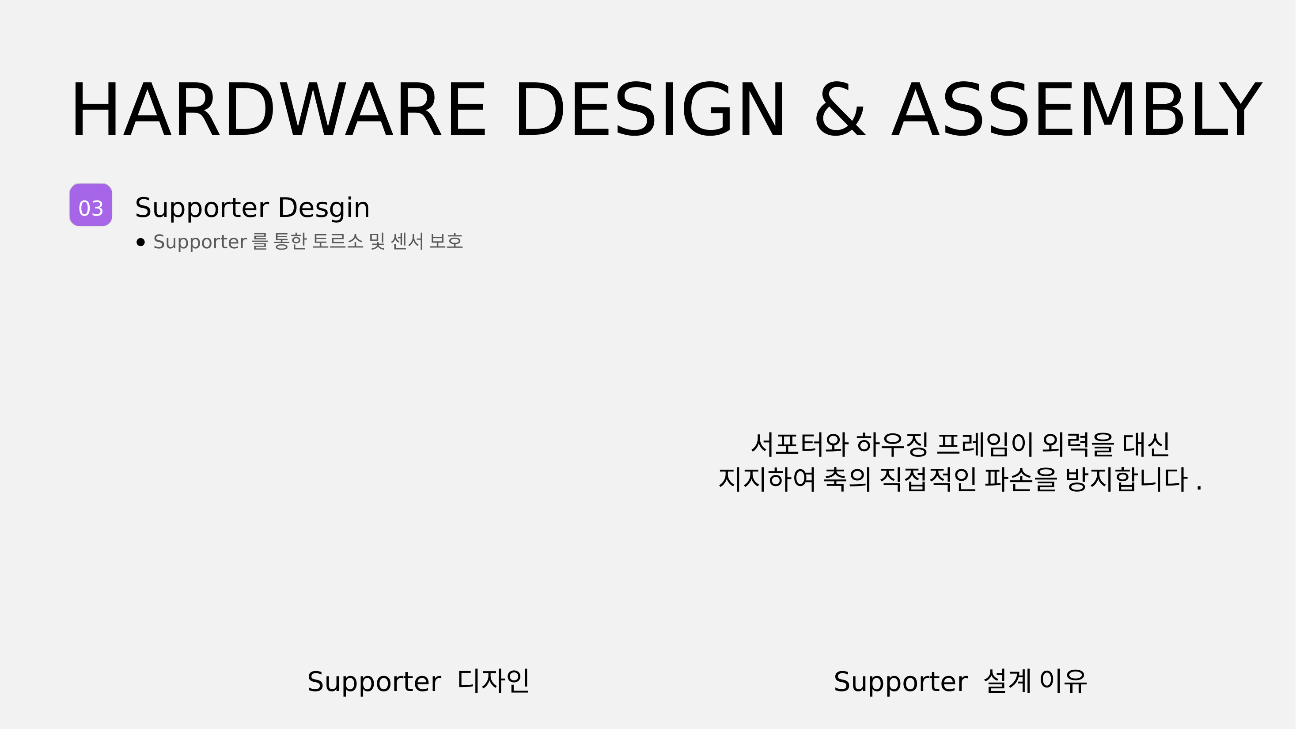
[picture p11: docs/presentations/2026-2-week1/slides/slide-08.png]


**Supporter** — 서포터와 하우징 프레임이 외력을 대신 지지해 축의 직접적인 파손을 방지.

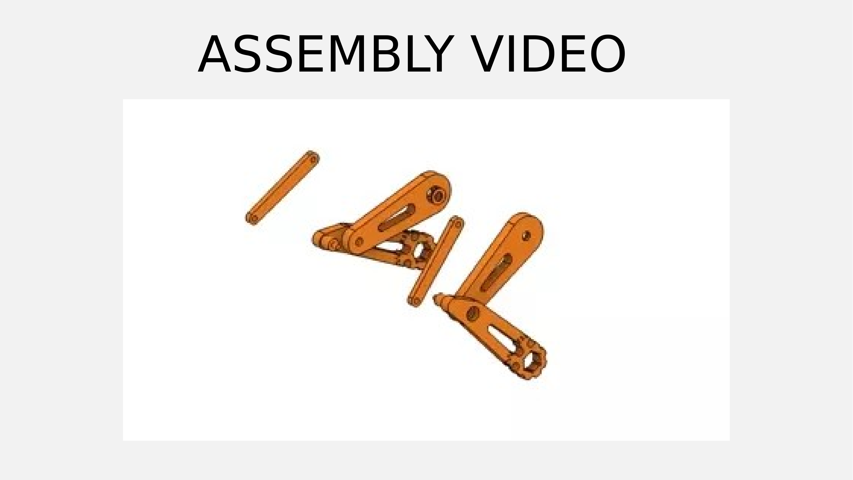
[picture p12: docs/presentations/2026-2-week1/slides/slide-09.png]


### Assembly Video

▶ **[어셈블리 애니메이션 (27 s)](../../../hardware/media/assembly-animation.mp4)**

---

## 04 — 모터 구동영상

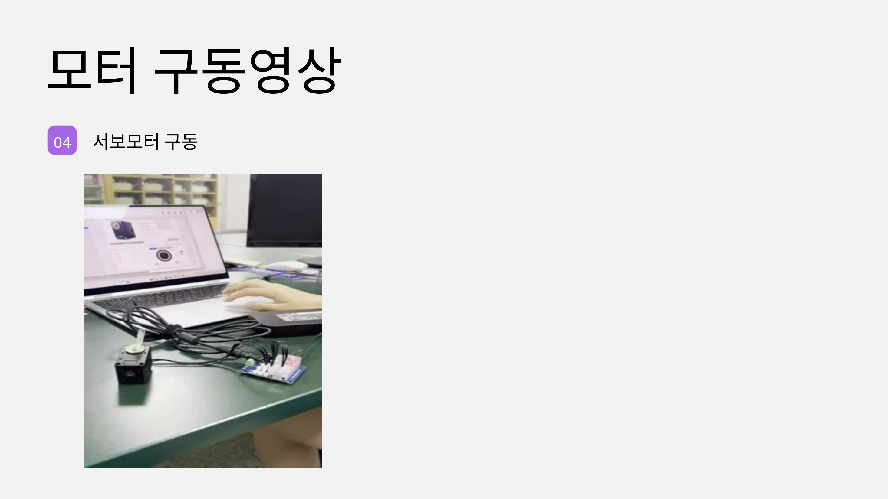
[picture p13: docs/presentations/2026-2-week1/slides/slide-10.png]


**서보모터 (AK45-36)** — [구동 영상](video/motor-servo-AK45.mp4)

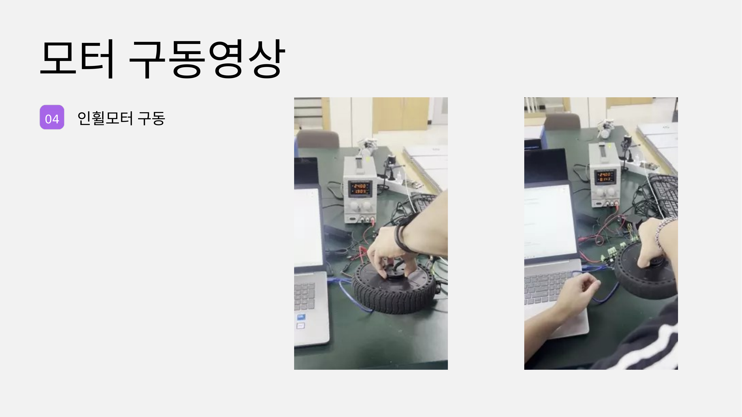
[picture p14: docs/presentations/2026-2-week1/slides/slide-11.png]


**인휠모터 (WA172E)** — [영상 1](video/motor-inwheel-1.mp4) · [영상 2](video/motor-inwheel-2.mp4)

---

## 05 — 하드웨어 제작 계획

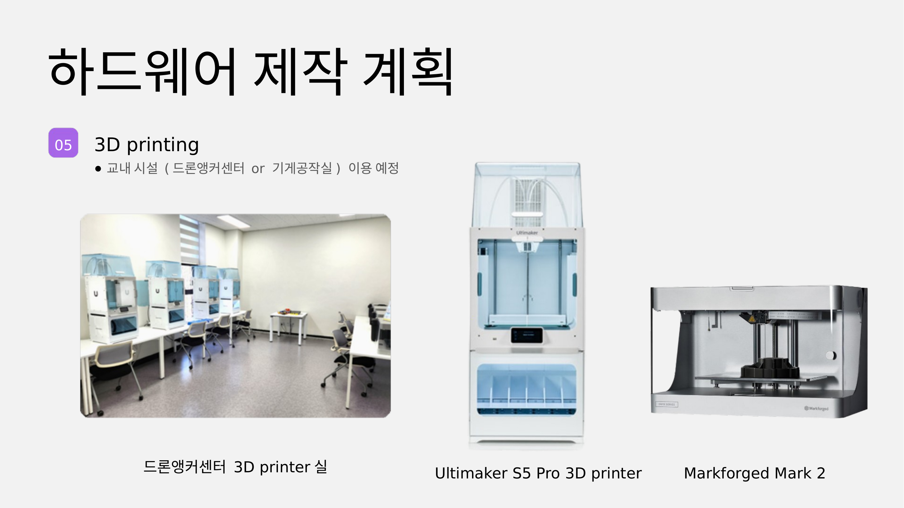
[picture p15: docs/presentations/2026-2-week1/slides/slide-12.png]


교내 시설(드론앵커센터 / 기계공작실) 이용 예정 — **Ultimaker S5 Pro**, **Markforged Mark 2**

> 발표 이후 Ultimaker S5(330×240×300) 기준으로 베드 적재를 다시 검토했습니다.
> 축정렬 bbox 로는 허벅지·정강이가 안 들어가지만 **회전시키면 전부 눕혀서 들어갑니다**
> (허벅지 166.25°, 정강이 9.75°, 보조링크 150.28°). 눕힘 + 벽 6줄 + 인필 20 % 확정.
> 상세: [`../../mechanical/04-print-orientation-infill.md`](../../mechanical/04-print-orientation-infill.md)
> · 슬라이서 설정: [`../../../hardware/print/README.md`](../../../hardware/print/README.md)

---

## 발표 이후 진행된 설계 변경

| 항목 | 발표 시점 | 현재 |
|---|---|---|
| 고관절 | 미정 | CubeMars AK45-36 V3.0 KV80 + 출력 허브 + 마운트 링 ([01](../../mechanical/01-hip-actuator-AK45.md)) → **2026-10 Damiao DM-J4340P-2EC 로 교체** ([05](../../mechanical/05-hip-actuator-DM4340P.md)) |
| 휠 체결 | 6 × Ø6 PCD54 (대응 탭홀 없음) | 4 × M6 PCD36 + Ø49.95 스피곳 |
| 부시 | 리니어부시 (회전 불가) | 오일리스/DU 부시 + 양단 탭 샤프트 3종 신설 |
| 질량 | — | 11.187 kg, CoG 지면 위 270.8 mm |
| 힙 토크 | — | 9.51 N·m @Δθ=0 (AK45 정격 8 의 119 %) → DM4340P 기준 9.59 N·m (정격 9 의 107 %) ([05](../../mechanical/05-hip-actuator-DM4340P.md)) |
| 3D 프린팅 | 방향 미정 | 눕힘 + 벽 6줄 + 인필 20 %, print-ready STL 6종 |

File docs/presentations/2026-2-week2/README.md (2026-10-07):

# 2026-2학기 2주차 발표 — 하드웨어 제작 및 시뮬레이션 결과 보고

2조 · 발표일 2026-09-14 · 슬라이드 16장 · 이전: [1주차](../2026-2-week1/) · 다음: [3주차](../2026-2-week3/)

- 전체 슬라이드 PDF: [`2026-2-week2.pdf`](2026-2-week2.pdf) (슬라이드 이미지로 재구성, 원본 `.pptx` 79 MB 는 미커밋)
- 영상은 H.264 / 최대 1280 px 로 재인코딩. 1주차와 같은 영상은 1주차 파일로 링크합니다.

## 목차

| # | 섹션 | 내용 |
|---|---|---|
| 01 | MATLAB Simulink (CoM 추가) | 스쿼트 / 주행+스쿼트 영상과 무게중심·피치 스코프, 서보 필요 토크 |
| — | Motion Simulation | 스쿼트, 전진·후진·밸런싱 |
| 02 | 링크부 체결 | MISUMI 부시·샤프트 결합, 링크별 부시 최소길이 |
| 03 | Assembly Video | 링크 부품 조립 |
| 04 | 3D 프린팅 | 링크부 출력 (고양시 드론앵커센터, 84,000원) |
| 05 | 모듈화 | 토르소 서보모터 / 다리 휠모터 구동 확인 |

---

## 01 — MATLAB Simulink (CoM 추가)

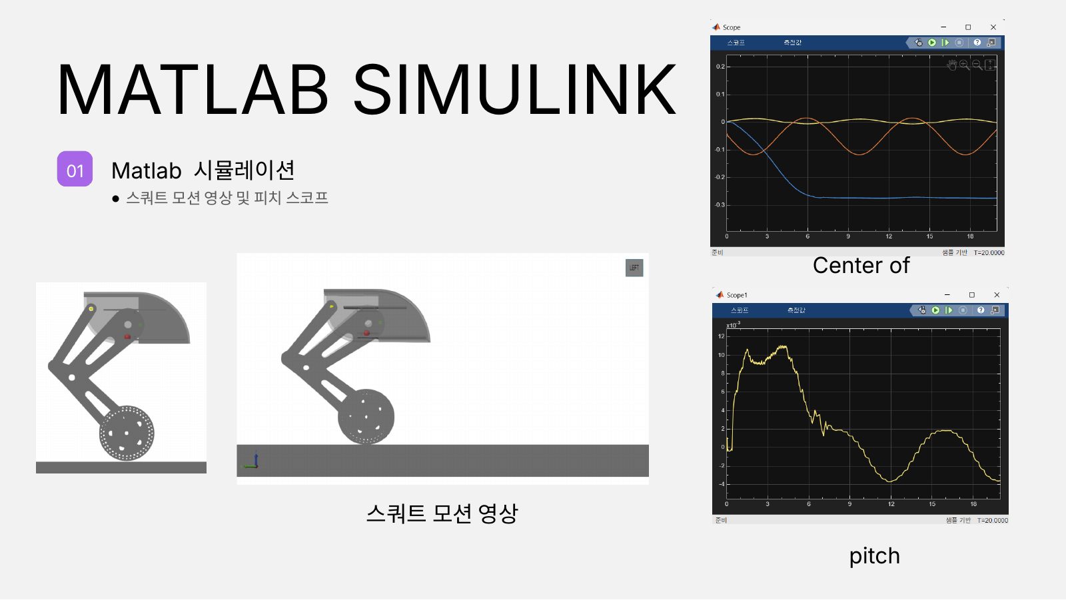
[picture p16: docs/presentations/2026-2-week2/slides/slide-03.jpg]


**스쿼트 모션 + 무게중심·피치 스코프** — [영상](video/sim-squat-cog-pitch.mp4)

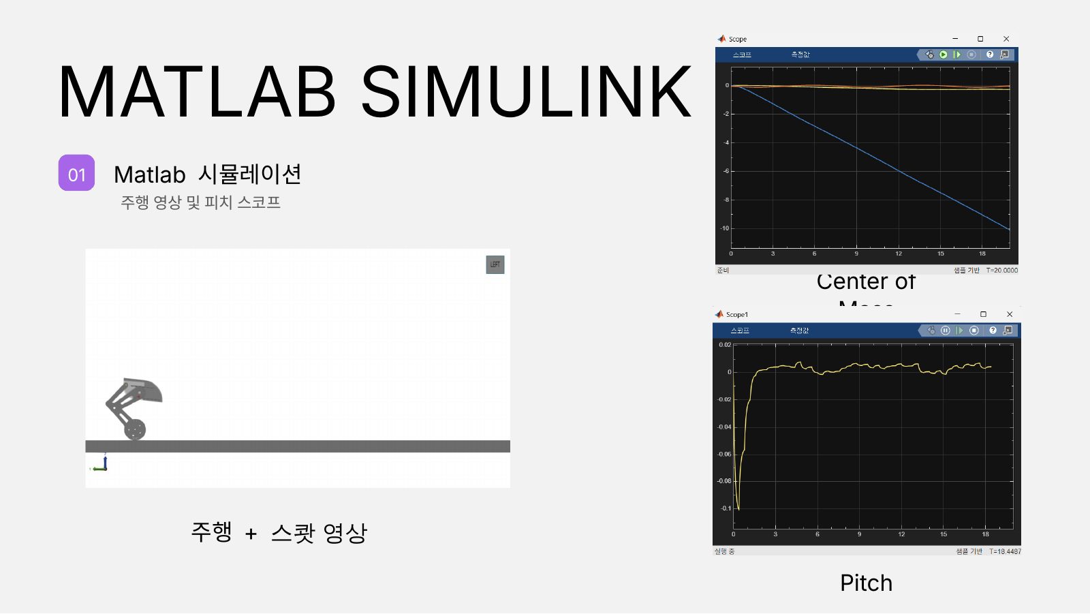
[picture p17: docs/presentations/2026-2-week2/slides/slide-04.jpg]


**주행 + 스쿼트, 피치 스코프** — [영상](video/sim-drive-squat-pitch.mp4)

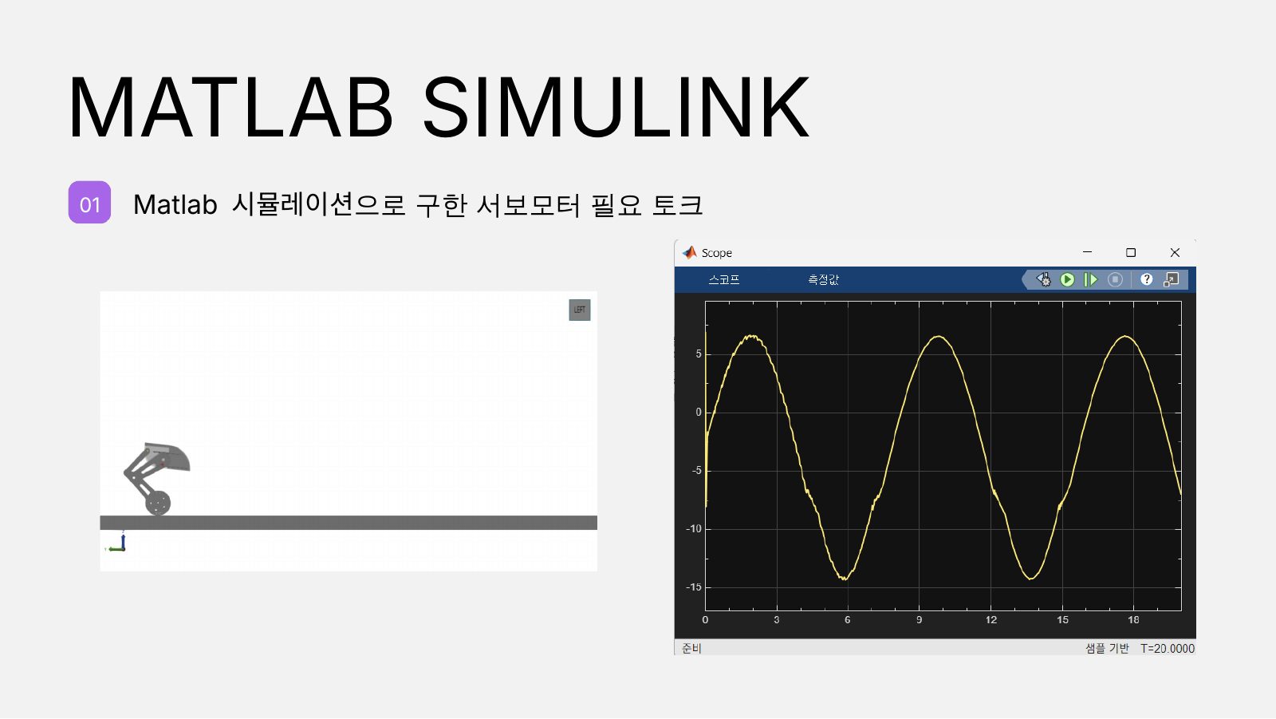
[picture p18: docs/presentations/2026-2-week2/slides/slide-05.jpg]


**Simulink 로 구한 서보모터 필요 토크** — 스쿼트 주기 동안 사인파 형태의 토크 프로파일.

## Motion Simulation

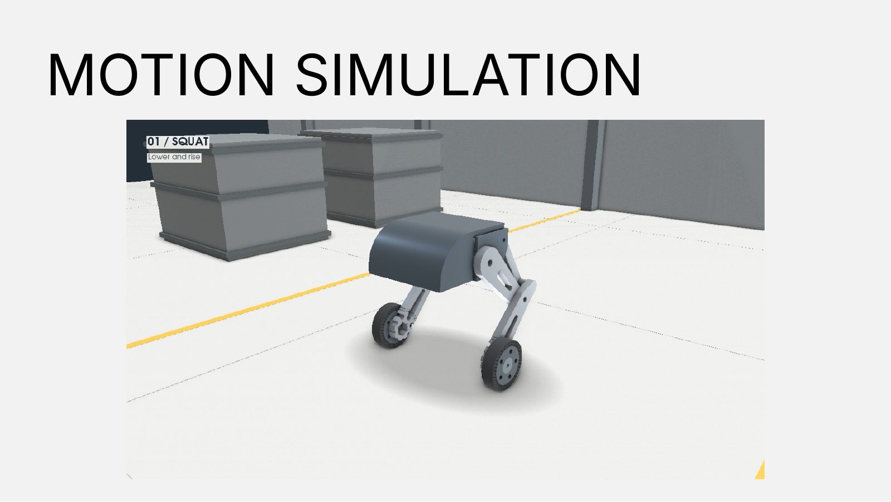
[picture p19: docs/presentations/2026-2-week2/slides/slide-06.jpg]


[01 / SQUAT](video/motion-sim-squat.mp4) · [FORWARD + REVERSE / BALANCING](video/motion-sim-drive-balance.mp4)

---

## 02 — 링크부 체결

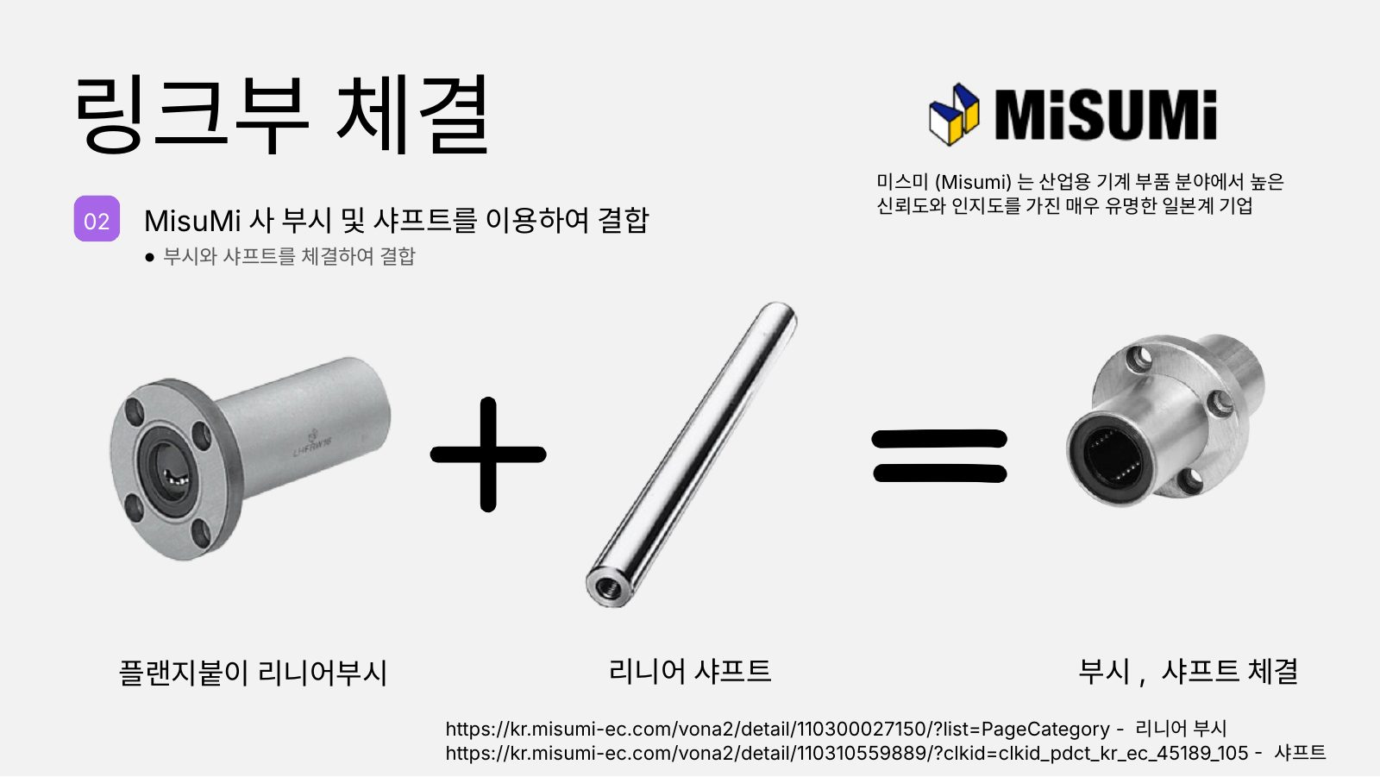
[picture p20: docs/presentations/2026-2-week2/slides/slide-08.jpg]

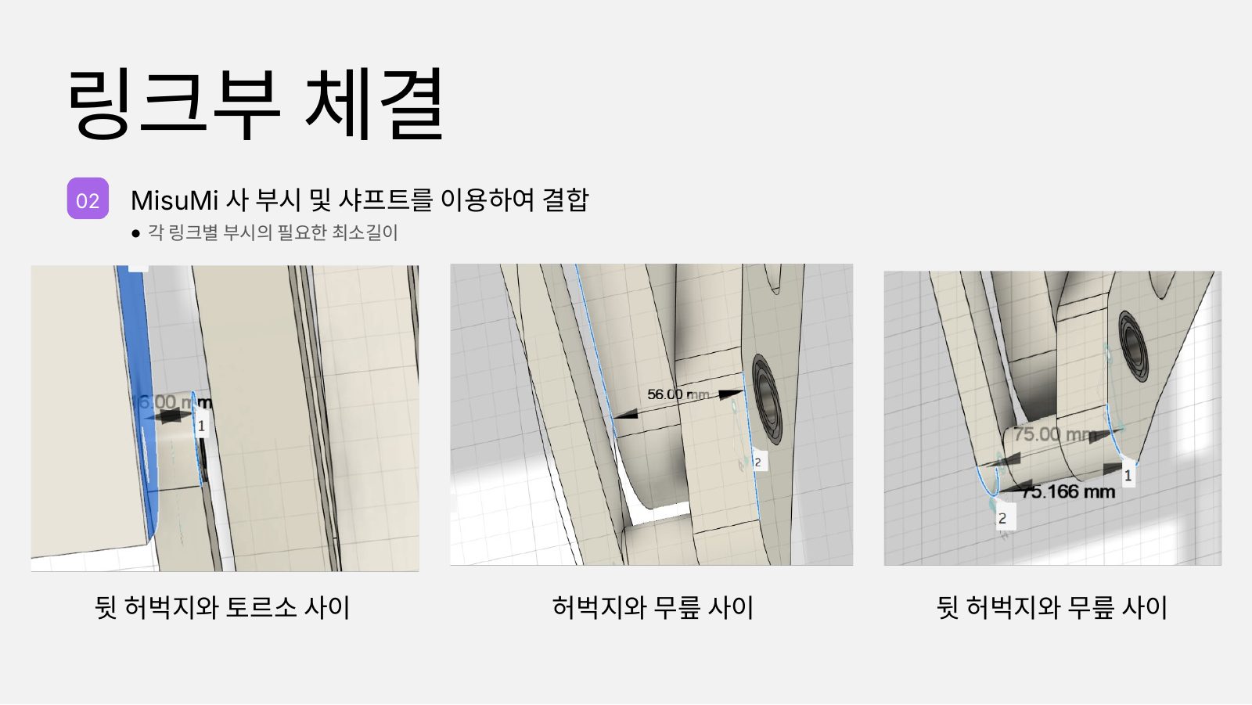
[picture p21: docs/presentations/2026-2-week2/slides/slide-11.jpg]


MISUMI 플랜지붙이 리니어부시 + 리니어 샤프트로 링크 조인트를 결합하고,
조인트별(뒷허벅지–토르소, 허벅지–무릎, 뒷허벅지–무릎) 부시 최소길이를 CAD 에서 측정.

> ⚠️ 리니어부시(볼 부시)는 직선 왕복용이라 요동 회전 조인트에서는 장기 유격 위험 — [02 §3](../../mechanical/02-joints-bushings-shafts.md).

## 03 — Assembly Video

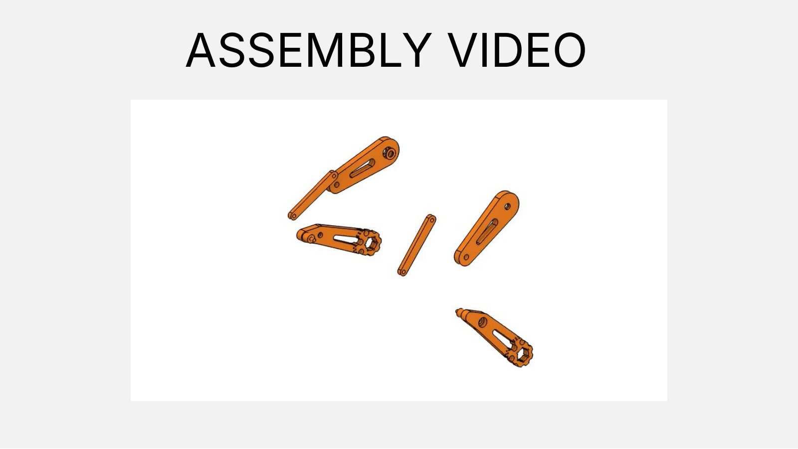
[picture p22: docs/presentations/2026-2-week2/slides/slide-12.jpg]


▶ [링크 부품 조립 영상 (27 s)](video/assembly-links.mp4)
· 최신 전체 어셈블리는 [v2 (36 s)](../../../hardware/media/assembly-animation-v2.mp4)

## 04 — 3D 프린팅

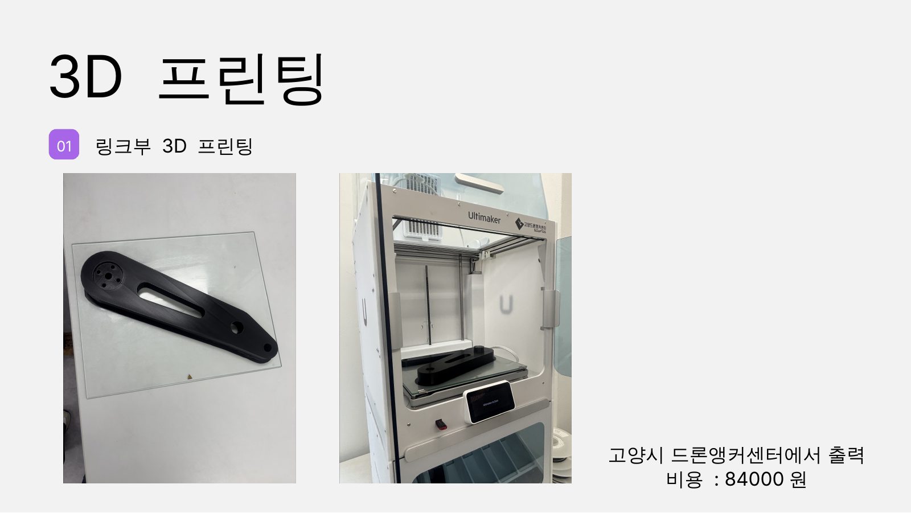
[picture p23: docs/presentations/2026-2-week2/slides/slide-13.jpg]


링크부를 **고양시 드론앵커센터** Ultimaker 로 출력 — 비용 **84,000원**.

## 05 — 모듈화: 각 모듈 구동 확인

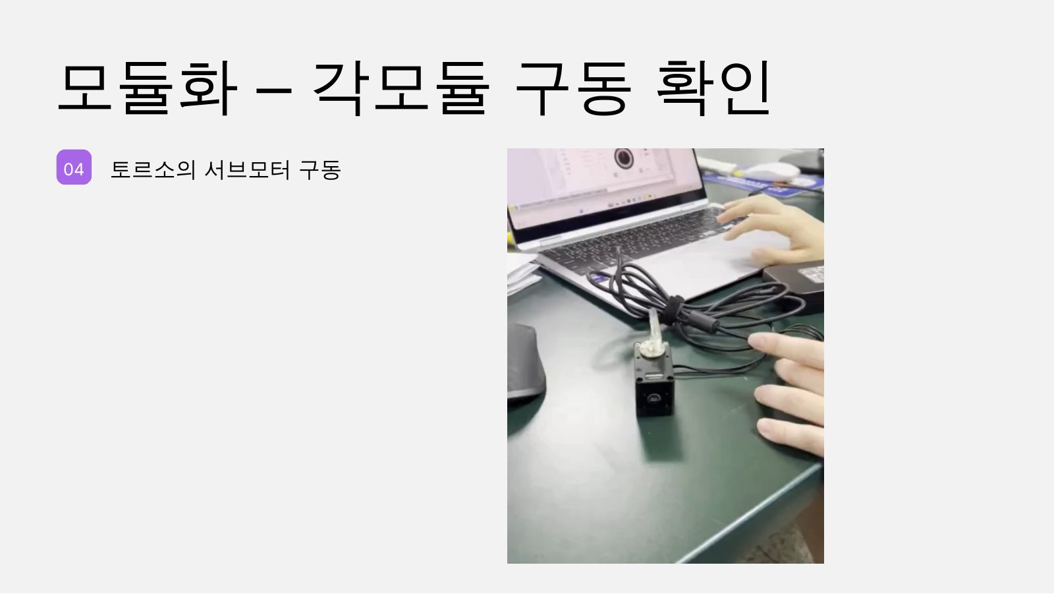
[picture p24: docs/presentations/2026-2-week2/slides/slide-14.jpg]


**토르소의 서보모터 구동** — [영상](../2026-2-week1/video/motor-servo-AK45.mp4) (1주차와 동일 영상)

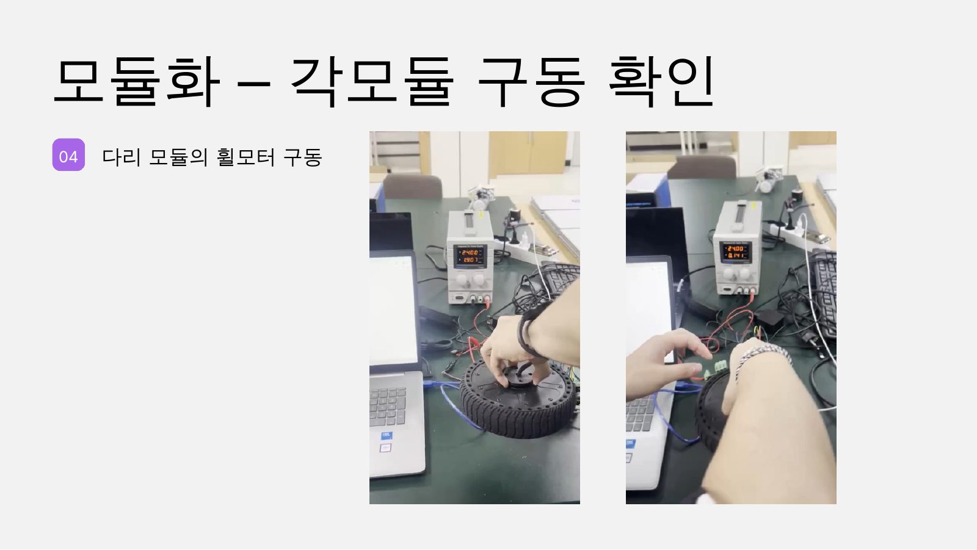
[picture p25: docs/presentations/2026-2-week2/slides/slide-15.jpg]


**다리 모듈의 휠모터 구동** — [영상 1](../2026-2-week1/video/motor-inwheel-1.mp4) · [영상 2](../2026-2-week1/video/motor-inwheel-2.mp4)

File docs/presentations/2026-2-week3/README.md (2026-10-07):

# 2026-2학기 3주차 발표 — 하드웨어 제작 및 센서 구동 테스트

2조 · 발표일 2026-09-21 · 슬라이드 23장 · 이전: [1주차](../2026-2-week1/) · [2주차](../2026-2-week2/)

- 전체 슬라이드 PDF: [`2026-2-week3.pdf`](2026-2-week3.pdf) (슬라이드 이미지로 재구성, 원본 `.pptx` 248 MB 는 미커밋)
- 영상은 H.264 / 최대 1280 px 로 재인코딩 (원본 중 2편은 HEVC 라 브라우저 재생 불가였음).
- 이 발표의 영상자료 3편(토르소 출력 시뮬레이션·어셈블리·쇼케이스)은 [`hardware/media/`](../../../hardware/media/) 에 원본 화질로 있습니다.

## 목차

| # | 섹션 | 내용 |
|---|---|---|
| 01 | 영상자료 | 토르소 3D 프린팅 시뮬레이션 · 어셈블리 · 모션/쇼케이스 |
| 02 | 서보모터 구동각 제한 · 정역학 · 동역학 | 조립·간섭·전달각 한계 → 권장 운용범위, 링크 정역학, T = 5 s 스쿼트 동역학 |
| 03 | 메인보드 부팅 / 환경 테스트 | LattePanda 선정, LattePanda → ODrive 휠 구동 |
| 04 | IMU 테스트 | BNO085 + Teensy 4.1, 쿼터니언 / Roll·Pitch·Yaw 출력, 호스트 파싱 코드 |

---

## 01 — 영상자료

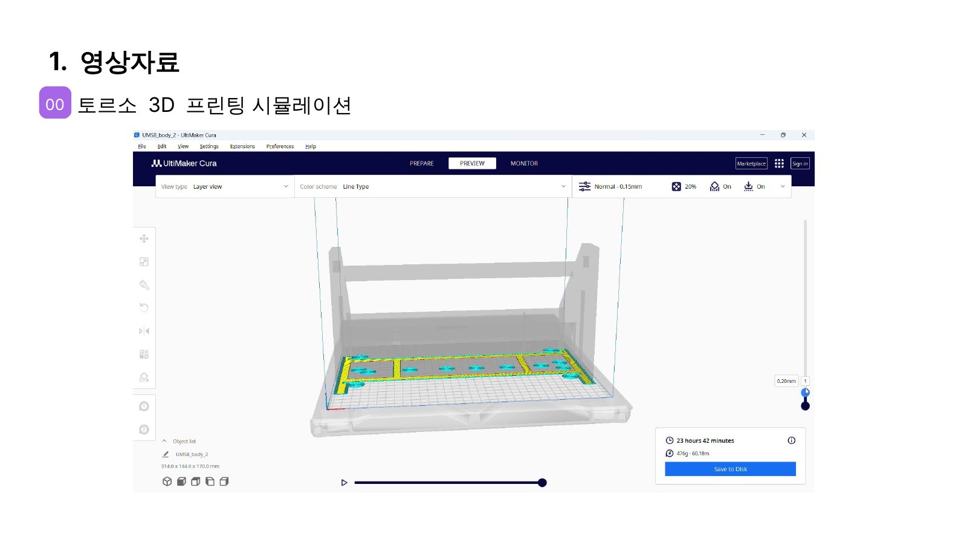
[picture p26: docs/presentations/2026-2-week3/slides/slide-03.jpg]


**토르소 3D 프린팅 시뮬레이션** (Ultimaker Cura, UM S5, `body_2`) — **23 h 42 min · 476 g · 60.18 m**
▶ [영상](../../../hardware/media/torso-print-sim-cura.mp4)



**Assembly** — 링크부(좌/우 다리) → 토르소부(상·하판, 88 mm 지지대, 배터리) → 링크부 + 몸체 결합
▶ [영상 (36 s)](../../../hardware/media/assembly-animation-v2.mp4)



**Motion / 쇼케이스** — 01 SQUAT (서보 축 높이 340–510 mm) · 02 ROLL (좌우 다리 독립 제어, 차체 기울기) ·
03 DRIVE (전진·후진·도립진자 밸런싱) · 04 TURN (휠 선회, 선회 시 기울기 보정)
▶ [영상 (42 s)](../../../hardware/media/motion-showcase.mp4)

---

## 02 — 서보모터 구동각 제한



세 조건을 모두 만족하는 구간을 구동 가능 구간으로 선정.

| 기준 | 펴는 쪽 | 접는 쪽 | 근거 |
|---|---|---|---|
| 조립 한계 (삼각형 BCD 성립) | +27.07° | −36.12° | 레버–보조링크 일직선 — [영상](video/kin-assembly-limit.mp4) |
| 간섭 한계 (RecurDyn) | +23.1° | −21.6° | [펴기](video/recurdyn-unfold.mp4) · [접기](video/recurdyn-fold.mp4) |
| 전달각 한계 (40°~140°) | +20.9° | −25.5° | Wilson, *Kinematics and Dynamics of Machinery* p.128 |
| **권장 운용범위** | **+20.9°** | **−21.6°** | [영상](video/operating-range.mp4) |



> 조립 한계 ±값은 저장소 기구학 해석(`hip_torque3.py`)의 기구학 한계 −27.08° / +36.12° 와 일치합니다
> (부호만 반대: 발표는 **+ = 펴짐**, 저장소는 **+ = 접힘**).

## 02 — 정역학 해석



- 해석 범위 Δφ = −21.6° ~ +20.9°, 하중: 토르소 3 kg → 다리 1개당 14.7 N, 링크 0.2/0.2/0.1 kg → 지면반력 19.6 N
- 가정: 정적 평형, 링크 무게중심은 중앙, 마찰·스프링 무시 — [자세별 하중 영상](video/statics-sweep.mp4)



**결과**: 접힐수록 모든 하중 증가 — 접힘 끝(Δφ = −21.6°)에서 보조링크 축력 85 N, 핀 반력 96 N,
**서보 토크 8.5 N·m 최대**. 압축이 없어 좌굴 우려 없음.
**판정**: 8.5 N·m < DM-J4340P 정격 9 N·m (95 %) → 구동 가능, 다만 여유가 작아 접힌 자세 장시간 유지는 지양.

> ⚠️ 저장소의 CAD 질량 모델(토르소·배터리·액추에이터 포함 BODY 4.6 kg)로 같은 자세를 계산하면 **14.5 N·m** 입니다.
> 차이는 토르소 질량 가정(3 kg)에서 옵니다 — [05 §3](../../mechanical/05-hip-actuator-DM4340P.md) 참고.
> 어느 쪽이든 피크 27 N·m 안이라 구동은 가능하지만, 연속 정격 판정이 달라집니다.

## 02 — 기구학 · 동역학



주기 T = 5.0 s 스쿼트에서 링크별 각속도·각가속도 계산.



토르소 관성 + 링크 관성을 넣은 뉴턴–오일러 동역학. T = 5 s 에서는 관성 영향이 작아
**동역학 토크 ≈ 정역학 토크 (최대 ≈ 8.6 N·m, 정격 9 N·m 이하)**, 지면반력 변동 19.3~20.1 N.

---

## 03 — 메인보드 부팅 / 환경 테스트



**LattePanda 선정 이유** — Windows 기반 Python/C++ 개발, 센서·MCU 확장성, 소형·경량 온보드 탑재,
고수준 연산(LattePanda)과 실시간 제어(Teensy 4.1)의 역할 분리.



**LattePanda → ODrive 휠 구동 테스트** — ▶ [영상](video/test-lattepanda-wheel.mp4)
설정 코드: [`host/odrive_wheel_config.odrivetool.py`](../../../host/odrive_wheel_config.odrivetool.py)

## 04 — IMU 테스트



**BNO085 → Teensy 4.1 → 메인보드** — ▶ [영상 1](video/test-imu-1.mp4) · [영상 2](video/test-imu-2.mp4) · [영상 3](video/test-imu-3.mp4)



Game Rotation Vector 쿼터니언을 CSV 로 송신, 호스트에서 파싱 → Roll/Pitch/Yaw 로 변환해 3축 자세 추정.

- Teensy 코드: [`firmware/teensy_bno085_quat/teensy_bno085_quat.ino`](../../../firmware/teensy_bno085_quat/teensy_bno085_quat.ino)
- 호스트 코드: [`host/imu_serial_reader.py`](../../../host/imu_serial_reader.py)

---

## 발표 이후 변경 (2026-10)

| 항목 | 발표 시점 | 현재 |
|---|---|---|
| 고관절 액추에이터 | 정역학 판정에 이미 DM-J4340P 사양(정격 9 N·m) 사용 | **Damiao DM-J4340P-2EC 확정** — AK45 배송 지연 ([05](../../mechanical/05-hip-actuator-DM4340P.md)) |
| BOM | — | [`hardware/bom/`](../../../hardware/bom/) — 총 1,184,795원 (3D 프린팅 별도), 루빅 링크 V3 는 서보 변경으로 제외 |

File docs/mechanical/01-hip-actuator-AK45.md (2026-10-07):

# 01 — 고관절 구동부 (AK45-36) & WA172E 휠 체결부

> ⚠️ **이전안입니다.** AK45-36 배송 지연으로 고관절 액추에이터를 **Damiao DM-J4340P-2EC** 로 변경했습니다 (2026-10).
> 변경 내용·재계산 토크·CAD 수정 필요 사항: [05 — 고관절 액추에이터 변경](05-hip-actuator-DM4340P.md).
> 아래의 WA172E 휠 체결부(§5)와 토르소 가공(§6) 내용은 그대로 유효합니다.

파일: `hardware/cad/TWLR_assembly_AK45.f3d`

## 1. 왜 출력 허브가 필요한가

원본 모델에는 고관절 축 방향으로 **19 mm 의 빈 구간**이 원래부터 있었습니다.

| X (좌측, mm) | 내용 |
|---|---|
| −154 | 토르소 끝판 외면 (Ø43 관통구) |
| −154 … −173 | **빈 구간 19 mm** |
| −173 … −201 | 허벅지 힙 디스크 (Ø102, Ø42 베어링 보어) |

그리고 "Ø37 출력면을 링크에 직접 붙인다"는 **기하학적으로 불가능**합니다.

- AK45 회전 출력면: 반경 **0 … 18.5 mm** (Ø37)
- 허벅지 힙 디스크 안쪽면: 중앙에 Ø42 베어링 보어가 있어 실제 면은 반경 **21 … 51 mm**
- 두 면은 반경 구간이 겹치지 않음 → 닿을 수가 없음

그래서 **출력 허브**를 신설해 Ø37(PCD27) → Ø70(PCD60) 으로 확장했습니다.
허브 플랜지 10 mm + 허브 축 22 mm = 정확히 19 mm 빈 구간을 메웁니다.

## 2. 구동 체인 (좌측 기준, 우측 대칭)

```
   허벅지 링크        출력 허브(신규)        AK45-36         마운트 링(신규)   토르소
  ┌──────────┐   ┌──────┬─────────┐   ┌───────────────┐  ┌────┐        ║
  │  Ø102    │───│ Ø70  │  Ø36    │───│ Ø37 │  Ø55    │──│Ø68 │════════║
  └──────────┘   └──────┴─────────┘   └───────────────┘  └────┘        ║
  -201    -173  -173  -163      -141 -141 -139     -84.5  -144  -139   -154
                       └ 토르소 Ø43 보어 관통 ┘                    (끝판)
```

| X 구간 [mm] | 부품 |
|---|---|
| −201 … −173 | `06_Thigh_L` 힙 디스크 |
| −173 … −163 | `21_HUB_Hip_Output` 플랜지 Ø70 × 10 |
| −163 … −141 | `21_HUB` 축 Ø36 × 22 — 토르소 Ø43 보어 관통 (편측 3.5 여유) |
| −142.5 … −141 | AK45 Ø18 h7 스피곳 × 1.5 |
| −141 … −139 | AK45 회전 출력 보스 Ø37 × 2 |
| −144 … −139 | `22_MNT_AK45_Ring` Ø68/Ø38 × 5 |
| −139 … −84.5 | AK45 하우징 Ø55 × 54.5 (전장 56.5) |
| −110 … −100 | 토르소 내부 격벽 — Ø56 관통 (하우징 통과 + 후단 2차 지지) |
| −84.5 … −76 | XT30PW / UART 커넥터 (배터리까지 8.5 여유) |

## 3. 서보 방향 검증 — 현재 배치가 맞습니다

CubeMars 공식 장착 문서가 없어 도면 기하학과 물리적 제약으로 판정했습니다.

1. **Ø37 단차의 존재** — 한 덩어리라면 단차가 생길 이유가 없습니다.
   Ø37 = 회전자 보스, 그 바깥 Ø37~Ø55 환상 = 고정자 면.
   Ø27 PCD(r=13.5)는 Ø37 보스 위 → **출력**, Ø48 PCD(r=24)는 환상면 위 → **하우징 고정**
2. **Ø18 h7 스피곳 + 3 × Ø4 다웰** — 공차 스피곳과 다웰은 토크 전달면의 특징.
   다웰이 큰 원이 아니라 작은 원 쪽에 있다는 건 작은 원이 더 큰 전단을 받는다는 뜻
3. **케이블** — XT30PW·UART 커넥터가 하우징에 붙어 있음. 뒤집으면 커넥터가 다리와 함께
   회전해 배선이 꼬여 끊어짐. 하우징 → 토르소, 출력 → 다리가 유일한 해

> CubeMars 제품 페이지의 3D STEP 을 받아 넣으면 1분 만에 확정됩니다.

## 4. 체결 사양 (좌/우 8쌍 전부 편차 0.000 mm)

| 체결 | 규격 | 스크루 |
|---|---|---|
| 링 ↔ AK45 하우징 | 6 × M3, PCD48 | M3×8 |
| 링 ↔ 토르소 끝판 | 6 × M4, PCD60 | M4×12, 탭 8 dp (**인서트 필수**) |
| 허브 ↔ AK45 출력 | 6 × M3, PCD27 + Ø18h7 스피곳 | M3×10 |
| 허브 ↔ 허벅지 링크 | 8 × M4, PCD60 | M4×35, 허브에 탭 |

> **M3 를 8개가 아니라 6개로 한 이유**: AK45-36 V3.0 출력 플랜지는 도면상
> `6-M3 × 4.5DP, PCD27 + Ø18h7 스피곳` 으로 고정되어 8개를 뚫을 수 없습니다.
> 요청하신 "8개"는 실제로 토크를 전달하는 **허브 ↔ 링크 인터페이스(8 × M4, PCD60)** 에
> 반영했고, PCD60 이면 같은 볼트로 전달 토크가 2.2배 커집니다.

## 5. WA172E 인휠모터 체결부

### 변경 전 문제
- Shin 패드에 6 × Ø6, PCD54 — 바퀴측에 대응 탭홀이 전혀 없었음
- 실제 인터페이스는 **4-M6 × 5DP, PCD36 + Ø50 스피곳**
- PCD36(r=18)은 Shin 의 기존 Ø50.04 관통보어 **안쪽** → 나사가 물릴 살이 없음

### 변경 내용
1. 기존 6 × Ø6 PCD54 **삭제**
2. Ø50.04 보어의 바깥 8 mm 를 메워 **볼트 착좌 웨브** 확보 (X ∓229 → ∓221)
3. **Ø49.95 × 6 파일럿 스피곳** 신설 (X ∓229 → ∓235) — 허브 카운터보어에 삽입, 동심 정렬
4. **4 × Ø6.6, PCD36** (45°/135°/225°/315°) 관통 — 스피곳 + 웨브 14 mm
5. 중앙 **Ø12** 케이블/축 관통

스크루: M6 소켓 4개, 유효길이 14(Shin) + 1.2(허브 웨브) + 5(모터 탭) → **M6 × 20~22**

## 6. 토르소 가공 (서보 장착에 물리적으로 불가피했던 2건)

| 변경 | 사유 |
|---|---|
| 내부 격벽 Ø56 관통 2곳 (\|X\| 100~110) | AK45 전장 56.5 vs 끝판~격벽 44 mm — 뚫지 않으면 장착 불가. 관통구가 하우징 후단의 2차 지지 역할도 함 |
| 끝판 내면 6 × M4 PCD60 탭 (좌우) | 마운트 링 고정. PCD48 로 직접 뚫으면 기존 Ø43 보어와 웨브가 0.8 mm 밖에 안 남아 링 방식 채택 |
| 허벅지 고아 바디 1개 제거 (X ∓154~∓156, 2 mm 링) | 허벅지 본체와 분리되어 떠 있던 바디, 허브 축 경로와 완전 간섭 |

그 외 부품(Part14/15/16, 배터리, 커플러, PCB, 6905/6904, 부싱)은 **체적까지 원본과 일치**함을 확인했습니다.

## 7. 검증

| 항목 | 결과 |
|---|---|
| 간섭 해석 (55 오컬런스) | 실질 간섭 **0건** (잔여 79건은 나사 산 모델링 + 원본에 원래 있던 2건) |
| 볼트 인터페이스 정합 | 좌/우 8쌍 전부 **편차 0.000 mm** |
| 원본 부품 체적 보존 | Part12 = 원본 − 의도한 절삭 50,466.6 mm³ ✓ / Part13·15·16 원본과 동일 ✓ |
| 대칭성 | 좌우 무게중심 X = 0.000 mm |

## 8. 링크의 기존 경량화 형상 (원본 유래)

종아리 휠 단부의 "톱니/허니컴" 형상은 원본 바디에 이미 있던 것으로, 세 가지가 겹쳐 보이는 것입니다.

| 형상 | 사양 | 판단 |
|---|---|---|
| 톱니형 외곽 | Ø22 × 8, PCD100 — 중심이 Ø90 패드 밖 5 mm 라 테두리를 파먹는 스캘럽. 노치 깊이 6 mm(r45→r39), 하나당 24° | **유지** — 하중 경로(PCD36) 바깥, 모멘트 ≈0 인 자유단. 약 85 cm³ 경량화 |
| 긴 슬롯 | 끝단 Ø30/Ø20, 중심간 101.5 mm | **유지** — 빔 중립축. 허벅지에도 동일. 약 85 cm³ |
| 작은 구멍 12개 | Ø5.5 × 6 @PCD140 + Ø4.5 × 6 @PCD156, 두 줄 엇갈림 | **제거 권장** — M5/M4 통과 치수로 원본에서 무언가를 볼트로 달던 흔적. 현재 무기능. 6.7 cm³(인쇄 3.7 g) 절감에 노치 12개 추가 |

## 9. 남은 권고

1. **6905 베어링 4개 무기능** — 허브 직결 구조라 내륜에 들어갈 축 없음. 제거 시 199 g 절감
2. **모멘트 지지 보강** — 허브 축을 Ø35 로 낮추고 토르소 끝판 보어를 Ø47 로 넓혀 **6807(35×47×7)** 삽입
3. **허브 재질** — AL6061 기준 132 g. 24 N·m 피크에서 Ø36 축 전단응력 2.6 MPa 로 여유 큼. **PLA 출력 비권장**
4. **AK45 STEP 확보 시 플레이스홀더 교체**

참고: [CubeMars AK45-36 V3.0 KV80](https://www.cubemars.com/ko/product/ak45-36-v3-0-kv80-robotic-actuator.html)

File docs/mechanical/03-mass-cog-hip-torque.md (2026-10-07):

# 03 — 질량 · 무게중심 · 고관절 토크

> **2026-10 갱신 — 고관절이 Damiao DM-J4340P-2EC 로 바뀌었습니다.** 스크립트 기본값이 DM4340P 입니다.
>
> | | AK45 (이 문서 §2~§6 의 표) | **DM4340P (현재)** |
> |---|---|---|
> | 총질량 / CoG 지면높이 | 11.187 kg / 270.8 mm | **11.239 kg / 271.5 mm** |
> | 직립 필요토크 | 9.51 N·m (정격 8 의 119 %) | **9.59 N·m (정격 9 의 107 %)** |
> | 연속 정격 유지 자세 | Δθ ≤ −20.0° | **Δθ ≤ −5.5°** |
> | 피크 도달 | +30.8° (24 N·m) | **+31.8° (27 N·m)** |
>
> 상세·전체 표: [05 — 고관절 액추에이터 변경](05-hip-actuator-DM4340P.md).
> 아래 본문은 질량 모델·계산 방법 설명과 AK45 기준 기록으로 남겨 둡니다.

재현: `hardware/analysis/mass_cog.py` → `hip_torque3.py` (`TWLR_ACT=AK45` 로 이전안 재현)
결과 스냅샷 (DM4340P): [`mass-and-cog.txt`](../../hardware/analysis/results/mass-and-cog.txt) ·
[`hip-torque.txt`](../../hardware/analysis/results/hip-torque.txt) ·
[`infill-sweep.txt`](../../hardware/analysis/results/infill-sweep.txt)
· AK45 기록: [`hip-torque_AK45.txt`](../../hardware/analysis/results/hip-torque_AK45.txt) ·
[`mass-and-cog_AK45.txt`](../../hardware/analysis/results/mass-and-cog_AK45.txt) ·
[`infill-sweep_AK45.txt`](../../hardware/analysis/results/infill-sweep_AK45.txt)

## 1. 질량 모델

3D 프린팅 부품은 솔리드가 아니므로 **셸 + 인필** 로 유효 충전율을 계산합니다.

```
V_shell = min(A · t_wall, V)                 A = 표면적, t_wall = 2.4 mm (벽 6줄)
f       = (V_shell + infill · (V − V_shell)) / V
m       = V · ρ_PLA · f                      ρ_PLA = 1.24 g/cm³
```

구매품(WA172E 2,200 g, AK45 349 g, 배터리 700 g)은 데이터시트/실측 고정값입니다.

## 2. 결과 (벽 6줄 / 인필 20 %, AK45 기준)

| 항목 | 값 |
|---|---|
| **총질량** | **11.187 kg** |
| **무게중심** | (0.0, +11.5, −151.2) mm — 고관절 원점 기준 |
| 지면 기준 CoG 높이 | **270.8 mm** |
| 휠축 기준 CoG 높이 | **184.8 mm** |
| 좌우 대칭 | X = 0.000 mm |

| 그룹 | 질량 |
|---|---|
| BODY (토르소·외장·배터리·PCB·AK45·마운트링) | 4.563 kg |
| THIGH (허벅지·허브·6905) | 1.149 kg |
| SHIN (종아리·휠·6904·부시) | 5.300 kg |
| COUP (보조링크·부시) | 0.176 kg |

> 질량의 절반 가까이가 SHIN 그룹인데, 그 중 4.4 kg 이 WA172E 휠 2개입니다.
> 다리 끝 관성이 커서 밸런싱 응답에 불리하지만 인휠 방식의 구조적 특성입니다.

## 3. 고관절 필요토크 — 가상일 원리

4절 링크를 폐쇄해로 풀고, 고관절 각도 Δθ 를 미소량 흔들었을 때의 위치에너지 변화로 구합니다.

```
τ_leg(Δθ) = ½ · dE_pot/dΔθ       (다리 1개당, ½ 은 좌우 분담)
E_pot(Δθ) = g · Σ mᵢ · zᵢ(Δθ)
```

각 부품의 위치는 그룹별로 다르게 변환합니다.
BODY 는 고정, THIGH 는 고관절 중심 회전 φ1, SHIN 은 무릎 중심 회전 φ2, COUP 은 A 중심 회전 φ3.
φ2·φ3 는 매 스텝 4절 폐쇄해를 0.25° 간격으로 연속 추적해 분기 오류를 막습니다.

모터 출력 토크상수 **Kt_out = 0.11 × 36 = 3.96 N·m/A** (정격 2 A → 7.9 N·m, 피크 6.5 A → 25.7 N·m)

## 4. 결과 (AK45 기준)

| 접힘 Δθ | 힙높이 | CoG높이 | 무릎각 | 필요토크 | 전류 | 정격 8 대비 | 피크 24 대비 | 허용듀티 | 판정 |
|---|---|---|---|---|---|---|---|---|---|
| −25° | 546 | 338 | 135.4° | 7.42 | 1.87 A | 93 % | 31 % | 100 % | 연속 가능 |
| **−20°** | 523 | 326 | 118.7° | **7.94** | 2.00 A | 99 % | 33 % | 100 % | **연속 한계** |
| −10° | 475 | 299 | 95.8° | 8.53 | 2.15 A | 107 % | 36 % | 86 % | 피크내 |
| **0°** | 422 | 271 | 76.3° | **9.51** | 2.40 A | **119 %** | 40 % | **69 %** | 피크내 |
| +10° | 361 | 238 | 57.5° | 10.98 | 2.77 A | 137 % | 46 % | 52 % | 피크내 |
| +20° | 289 | 200 | 37.7° | 13.68 | 3.45 A | 171 % | 57 % | 34 % | 피크내 |
| +30° | 191 | 146 | 12.9° | 22.31 | 5.63 A | 279 % | 93 % | 13 % | 피크내 |
| **+30.8°** | 181 | 140 | 10.4° | **24.00** | 6.06 A | 300 % | **100 %** | — | **피크 한계** |
| +31° | 178 | 139 | 9.7° | 24.52 | 6.19 A | 307 % | 102 % | 10 % | 불가 |

기구학 한계: 신전 **Δθ = −27.08°** (힙높이 552 mm) / 접힘 **Δθ = +36.12°** (힙높이 32 mm)

## 5. 판정

- **직립 자세(Δθ = 0)에서 정격 8 N·m 를 19 % 초과**합니다. 피크의 40 % 이므로 **버티지만 연속은 아닙니다.**
  I² 기준 허용 듀티 **69 %** — 계속 서 있으면 모터가 뜨거워집니다.
- **연속 정격 안에서 서 있으려면 Δθ ≤ −20°** (다리를 더 편 자세, 힙높이 523 mm 이상)로 세워야 합니다.
- **앉는 동작은 Δθ = +30.8° 까지만.** 그 이상은 피크 토크로도 못 버팁니다.

### 대책 (택 1 또는 병행)
1. **다리를 편 자세를 기본으로** — 제어 목표 자세를 Δθ ≈ −20° 로 잡으면 연속 정격 안
2. **스프링 어시스트** — 무릎 또는 A-B 사이에 **k ≈ 4.5 N/mm** 코일 스프링을 넣어 중력 토크를 상쇄
3. **경량화** — 인필을 낮추면 직접적으로 효과 (아래)

## 6. 인필/벽이 토크에 미치는 영향

| 벽 | 인필 | 총질량 | CoG 지면높이 | 링크 6개 PLA | τ_hip @Δθ=0 | 정격 대비 |
|---|---|---|---|---|---|---|
| 2.4 | 15 % | 11.036 kg | 270.0 mm | 1,485 g | 9.34 N·m | 117 % |
| **2.4** | **20 %** | **11.187 kg** | **270.8 mm** | **1,587 g** | **9.51 N·m** | **119 %** |
| 2.4 | 30 % | 11.491 kg | 272.4 mm | 1,791 g | 9.85 N·m | 123 % |
| 2.4 | 40 % | 11.794 kg | 273.9 mm | 1,996 g | 10.19 N·m | 127 % |
| 4.0 | 20 % | 12.525 kg | 280.3 mm | 2,216 g | 11.18 N·m | 140 % |
| 4.0 | 40 % | 12.797 kg | 280.6 mm | 2,467 g | 11.44 N·m | 143 % |

**벽 6줄 → 10줄이 인필 20 %→40 % 보다 훨씬 비쌉니다** (+1.34 kg, +18 % 토크).
링크를 눕혀서 출력하면 벽 6줄 / 인필 20 % 로 강도가 확보되므로 여기가 최적점입니다
(→ [04](04-print-orientation-infill.md)).

## 7. 휠모터 자세복원 토크 (참고)

직립 자세, 총질량 11.19 kg, 휠축 위 CoG 185 mm 기준 — 기울기를 되세우는 데 필요한 휠 1개 토크.

| 기울기 | 휠 1개 필요토크 | 정격 5 N·m 대비 | 스톨 13 N·m 대비 |
|---|---|---|---|
| 5° | 0.88 N·m | 18 % | 7 % |
| 10° | 1.76 N·m | 35 % | 14 % |
| 20° | 3.47 N·m | 69 % | 27 % |
| 30° | 5.07 N·m | 101 % | 39 % |

30° 까지 기울어도 정격 안에서 복원 가능합니다. **밸런싱은 휠이 아니라 고관절이 병목입니다.**

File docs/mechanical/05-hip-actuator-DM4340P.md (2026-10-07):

# 05 — 고관절 액추에이터 변경: CubeMars AK45-36 → Damiao DM-J4340P-2EC

> 상태: **변경 확정 (2026-10)** · 구매처 [디바이스마트 #16019401](https://www.devicemart.co.kr/goods/view?no=16019401) · 2개 635,200원
> 이전안 문서: [01 — 고관절 구동부 (AK45-36)](01-hip-actuator-AK45.md) (CAD 파일명 `TWLR_assembly_AK45` 은 그대로)

## 1. 왜 바꿨나

AK45-36 의 **배송이 지연**되어 일정 안에 받을 수 없게 되면서, 국내 재고가 있는 Damiao
DM-J4340P-2EC 로 교체했습니다. 결과적으로 사양도 이쪽이 유리합니다.

| 항목 | AK45-36 V3.0 KV80 (이전) | **DM-J4340P-2EC 24V (현재)** | 비고 |
|---|---|---|---|
| 감속비 | 36 : 1 | **40 : 1** | 유성기어 |
| 정격 토크 | 8 N·m | **9 N·m** | +12.5 % |
| 피크 토크 | 24 N·m | **27 N·m** | +12.5 % |
| 정격 / 피크 전류 | 2 A / 6.5 A | 3.0 A / 8 A (24 V) | |
| 정격 속도 / 무부하 | — | 36 rpm / 52 rpm (24 V) | |
| 외형 | Ø55 × 56.5 mm | **Ø57 × 56.5 mm** | 길이 동일, 지름 +2 mm |
| 질량 | 349 g | **375 g** (판매처별 375~381 g 표기) | 2개 합 +52 g |
| 엔코더 | — | 14-bit 자기식 **듀얼** (출력축 단회전 절대위치) | 전원 투입 시 원점 복귀 불필요 |
| 출력 베어링 | — | **크로스 롤러 베어링** (P 모델의 차이점) | 고관절 캔틸레버 모멘트에 유리 |
| 통신 | CAN | **CAN 1 Mbps** / UART 921600 (튜닝) | MIT · 위치-속도 · 속도 · 힘-위치 혼합 모드 |
| 보호 | — | 과전압 ≤32 V(24 V형) · 저전압 <15 V · 드라이버 과열 ≥120 °C · CAN 통신 두절 시 Disable | |

사양 출처: 3주차 발표 슬라이드 16의 *DM-J4340P-2EC Motor Specification Table*,
[openelab 제품 페이지](https://openelab.io/products/damiao-brushlesdamiao-brushless-dm-j4340p),
[rcdrone 제품 페이지](https://rcdrone.top/products/damiao-dm-j4340p-2ec-servo-motor).

### 배터리와의 궁합
배터리는 **6S LiPo 22.2 V 5200 mAh** (만충 25.2 V). 24 V 형의 과전압 보호 32 V 까지
**6.8 V 여유**, 저전압 보호 15 V 는 6S 방전 하한(≈19.8 V)보다 낮아 정상 범위에서 꺼지지 않습니다.
회생제동 시 버스 전압이 순간적으로 올라갈 수 있으므로 감속 동작에서 전압을 모니터링할 것.

## 2. 고관절 필요토크 재계산

같은 CAD 질량 모델(벽 6줄 / 인필 20 %)에서 액추에이터 질량만 375 g 으로 바꿔 다시 돌렸습니다.

```bash
cd hardware/analysis
python3 mass_cog.py && python3 hip_torque3.py              # DM4340P (기본)
TWLR_ACT=AK45 python3 mass_cog.py && TWLR_ACT=AK45 python3 hip_torque3.py   # 이전안 재현
```

결과: [`hip-torque.txt`](../../hardware/analysis/results/hip-torque.txt) ·
[`mass-and-cog.txt`](../../hardware/analysis/results/mass-and-cog.txt) ·
이전 AK45 결과는 `*_AK45.txt` 로 보존.

| 항목 | AK45 | **DM4340P** |
|---|---|---|
| 총질량 | 11.187 kg | **11.239 kg** |
| CoG 지면 높이 | 270.8 mm | **271.5 mm** |
| 직립(Δθ=0) 필요토크 | 9.51 N·m = 정격의 **119 %** | **9.59 N·m = 정격의 107 %**, 피크의 36 % |
| 정격 안에서 연속 유지 가능한 자세 | Δθ ≤ **−20.0°** (힙높이 ≥ 523 mm) | Δθ ≤ **−5.5°** (힙높이 ≥ 452 mm) |
| 피크 토크 도달 | Δθ = +30.8° | Δθ = **+31.8°** |
| 직립 허용 듀티 (I² 기준) | 69 % | **88 %** |

| 접힘 Δθ | 힙높이 | 필요토크 | 정격 9 대비 | 피크 27 대비 | 판정 |
|---|---|---|---|---|---|
| −25° | 546 mm | 7.49 N·m | 83 % | 28 % | 연속 가능 |
| −20° | 523 mm | 8.00 N·m | 89 % | 30 % | 연속 가능 |
| −10° | 475 mm | 8.61 N·m | 96 % | 32 % | 연속 가능 |
| **−5.5°** | 452 mm | **9.00 N·m** | 100 % | 33 % | **연속 한계** |
| 0° | 422 mm | 9.59 N·m | 107 % | 36 % | 단시간 |
| +10° | 361 mm | 11.08 N·m | 123 % | 41 % | 단시간 |
| +20° | 289 mm | 13.80 N·m | 153 % | 51 % | 단시간 |
| +30° | 191 mm | 22.50 N·m | 250 % | 83 % | 단시간 |
| **+31.8°** | 166 mm | **27.00 N·m** | 300 % | 100 % | **피크 한계** |

부호: 이 저장소는 **+ = 접힘 (앉기)**. 3주차 발표의 Δφ 는 **+ = 펴짐** 이라 부호가 반대입니다.

### 팀 권장 운용범위(3주차 발표)와 대조

3주차 발표의 권장 운용범위 Δφ = −21.6°(접힘) … +20.9°(펴짐) 를 이 저장소 부호로 바꾸면
Δθ = −20.9° … +21.6° 입니다.

| 끝점 | 필요토크 (CAD 질량 모델) | 정격 대비 | 피크 대비 |
|---|---|---|---|
| 펴짐 끝 Δθ = −20.9° (힙높이 528 mm) | 7.96 N·m | 88 % | 29 % |
| 접힘 끝 Δθ = +21.6° (힙높이 276 mm) | **14.50 N·m** | **161 %** | 54 % |

→ **운용범위 전체가 피크 27 N·m 안**에 들어옵니다 (AK45 였다면 접힘 끝이 피크 24 N·m 의 약 60 %).
접힘 끝에서는 정격의 1.6 배라 **오래 앉아 있는 자세는 피해야** 한다는 결론은 같습니다.

## 3. ⚠️ 팀 정역학(3주차)과 숫자가 다른 이유 — 확인 필요

| | 3주차 발표 정역학/동역학 | 이 저장소 (CAD 질량 모델) |
|---|---|---|
| 하중 | 토르소 **3 kg** (다리 1개당 14.7 N) + 링크 0.5 kg → 지면반력 19.6 N | 부품별 실측 체적·재질로 **BODY 4.62 kg** (배터리 0.7, 액추에이터 0.75 포함), 전체 11.24 kg |
| 최대 토크 | 접힘 끝에서 **8.5 N·m** (정적) / 동역학 T = 5 s 스쿼트도 ≈ 8.6 N·m | 접힘 끝 **14.5 N·m** |
| 판정 | 정격 9 N·m 의 95 % → 구동 가능 | 정격의 161 % → 단시간만 |

두 해석의 차이는 대부분 **토르소 질량 가정(3 kg vs 4.6 kg)** 과 링크 질량에서 옵니다.
토르소가 아크릴 + 3D 프린팅으로 재설계되었으므로(쇼케이스 영상의 모델), **실제 토르소 무게를 저울로 재서
한쪽으로 맞추는 것**이 다음 단계입니다. 토르소가 3 kg 이면 팀 결과, 4.6 kg 이면 이 표가 맞습니다.

## 4. 기구 변경 필요 사항 (CAD 미반영)

현재 Fusion 모델(`hardware/cad/TWLR_assembly_AK45.f3d`)의 고관절 인터페이스는 AK45 기준입니다.

| 항목 | AK45 기준 현재 설계 | DM4340P 로 바꿀 때 |
|---|---|---|
| 토르소 내부 격벽 관통 | Ø56 | 하우징 Ø57 → **Ø58 이상으로 확대** |
| `22_MNT_AK45_Ring` (하우징 고정) | 6 × M3, PCD48 | **Damiao 설치도면의 하우징 체결 패턴으로 재설계** |
| `21_HUB_Hip_Output` (출력 허브) | 6 × M3, PCD27 + Ø18 h7 스피곳 + 3 × Ø4 다웰 | **출력 플랜지 패턴/스피곳 치수 확인 후 재설계** |
| 볼트 마찰 전달 검토 (`bolt_check.py`) | 피크 24 N·m 기준 | 피크 **27 N·m** 로 재검토 (허브↔출력은 다웰 전제 유지) |
| 커넥터 / 배선 | XT30PW + UART | 전원 + **CAN (Teensy 4.1 ↔ CAN 트랜시버)** |

> 출력/하우징 체결 패턴은 판매 페이지에 수치가 없고 제조사 설치도면(다운로드)에만 있습니다.
> 도면 확보 후 `21_HUB`, `22_MNT` 두 부품만 바꾸면 되도록 허브/링 구조는 그대로 둡니다.

## 5. 제어 측면

- **절대위치 듀얼 엔코더** → 부팅 시 다리 각도를 바로 알 수 있어 원점 탐색 동작이 필요 없음
- **MIT 모드** (위치·속도·Kp·Kd·피드포워드 토크 동시 지령) → 다리 임피던스 제어와 중력 보상 토크를 한 프레임으로 전송
- 구성 계획 (BOM 기준): Teensy 4.1 + CAN 트랜시버로 좌·우 DM4340P 와 CAN 1 Mbps 통신, LattePanda 는 USB 시리얼로 Teensy 에 목표 자세·속도 전달 (3주차 발표의 상·하위 제어기 역할 분리)

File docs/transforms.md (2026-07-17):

# Transformation Matrices - TWLR

Homogeneous transformation matrices between consecutive frames.
Convention: URDF RPY (XYZ extrinsic / ZYX intrinsic).

## Notation

### Frames

| Index | Link |
|---|---|
| $L_{0}$ | base_link |
| $L_{1}$ | link1_right |
| $L_{2}$ | link3_right |
| $L_{3}$ | link1_left |
| $L_{4}$ | wheel_right |
| $L_{5}$ | link3_left |
| $L_{6}$ | wheel_left |

### Joint Variables

| Variable | Joint | Type | From | To |
|---|---|---|---|----|
| $q_{1}$ | hip_right | continuous (rad) | $L_{0}$ | $L_{1}$ |
| $q_{2}$ | knee_right | continuous (rad) | $L_{1}$ | $L_{2}$ |
| $q_{3}$ | hip_left | continuous (rad) | $L_{1}$ | $L_{3}$ |
| $q_{4}$ | wheel_right | continuous (rad) | $L_{2}$ | $L_{4}$ |
| $q_{5}$ | knee_left | continuous (rad) | $L_{3}$ | $L_{5}$ |
| $q_{6}$ | wheel_left | continuous (rad) | $L_{5}$ | $L_{6}$ |

Shorthand: $c_i = \cos(q_i)$, $s_i = \sin(q_i)$

### Kinematic Tree

```
L0: base_link
  +-- [continuous] hip_right (q1)
      L1: link1_right
        |-- [continuous] knee_right (q2)
        |   L2: link3_right
        |     +-- [continuous] wheel_right (q4)
        |         L4: wheel_right
        +-- [continuous] hip_left (q3)
            L3: link1_left
              +-- [continuous] knee_left (q5)
                  L5: link3_left
                    +-- [continuous] wheel_left (q6)
                        L6: wheel_left
```

## Transforms

## hip_right

$L_{0}$ **base_link** -> $L_{1}$ **link1_right** (continuous)
  Variable: $q_{1}$

- **origin xyz**: (0.12337, -0.038877, 0.160846) m
- **origin rpy**: (-0.619267, 0, 0) rad
- **axis**: (1, 0, 0)

### Local Transform

$T^{0}_{1}(q_{1}) = T_{fixed} \cdot R_{axis}(q_{1})$ where:

$$
T_{fixed} = \begin{bmatrix}
1 & 0 & 0 & 0.12337 \\
0 & 0.814304 & 0.580438 & -0.038877 \\
0 & -0.580438 & 0.814304 & 0.160846 \\
0 & 0 & 0 & 1 \\
\end{bmatrix}
$$

$$
R_{axis}(q_{1}) = \begin{bmatrix}
1 & 0 & 0 & 0 \\
0 & c_{1} & -s_{1} & 0 \\
0 & s_{1} & c_{1} & 0 \\
0 & 0 & 0 & 1 \\
\end{bmatrix}
$$

---

## knee_right

$L_{1}$ **link1_right** -> $L_{2}$ **link3_right** (continuous)
  Variable: $q_{2}$

- **origin xyz**: (0, 0.163205, -0.117321) m
- **origin rpy**: (-2.089403, 0, 0) rad
- **axis**: (1, 0, 0)

### Local Transform

$T^{1}_{2}(q_{2}) = T_{fixed} \cdot R_{axis}(q_{2})$ where:

$$
T_{fixed} = \begin{bmatrix}
1 & 0 & 0 & 0 \\
0 & -0.495671 & 0.868511 & 0.163205 \\
0 & -0.868511 & -0.495671 & -0.117321 \\
0 & 0 & 0 & 1 \\
\end{bmatrix}
$$

$$
R_{axis}(q_{2}) = \begin{bmatrix}
1 & 0 & 0 & 0 \\
0 & c_{2} & -s_{2} & 0 \\
0 & s_{2} & c_{2} & 0 \\
0 & 0 & 0 & 1 \\
\end{bmatrix}
$$

---

## hip_left

$L_{1}$ **link1_right** -> $L_{3}$ **link1_left** (continuous)
  Variable: $q_{3}$

- **origin xyz**: (0, 0, 0) m
- **origin rpy**: (0.060327, 0, 0) rad
- **axis**: (1, 0, 0)

### Local Transform

$T^{1}_{3}(q_{3}) = T_{fixed} \cdot R_{axis}(q_{3})$ where:

$$
T_{fixed} = \begin{bmatrix}
1 & 0 & 0 & 0 \\
0 & 0.998181 & -0.060291 & 0 \\
0 & 0.060291 & 0.998181 & 0 \\
0 & 0 & 0 & 1 \\
\end{bmatrix}
$$

$$
R_{axis}(q_{3}) = \begin{bmatrix}
1 & 0 & 0 & 0 \\
0 & c_{3} & -s_{3} & 0 \\
0 & s_{3} & c_{3} & 0 \\
0 & 0 & 0 & 1 \\
\end{bmatrix}
$$

---

## wheel_right

$L_{2}$ **link3_right** -> $L_{4}$ **wheel_right** (continuous)
  Variable: $q_{4}$

- **origin xyz**: (0.039494, -0.006035, 0.007648) m
- **origin rpy**: (-3.141593, 0.991862, 1.570796) rad
- **axis**: (0.309017, 0, -0.951057)

### Local Transform

$T^{2}_{4}(q_{4}) = T_{fixed} \cdot R_{axis}(q_{4})$ where:

$$
T_{fixed} = \begin{bmatrix}
0 & 1 & 0 & 0.039494 \\
0.547132 & 0 & -0.837046 & -0.006035 \\
-0.837046 & 0 & -0.547132 & 0.007648 \\
0 & 0 & 0 & 1 \\
\end{bmatrix}
$$

$$
R_{axis}(q_{4}) = \begin{bmatrix}
c_{4} & s_{4} & 0 & 0 \\
-s_{4} & c_{4} & 0 & 0 \\
0 & 0 & 1 & 0 \\
0 & 0 & 0 & 1 \\
\end{bmatrix}
$$

---

## knee_left

$L_{3}$ **link1_left** -> $L_{5}$ **link3_left** (continuous)
  Variable: $q_{5}$

- **origin xyz**: (0, 0.155835, -0.126947) m
- **origin rpy**: (0, 0, 0) rad
- **axis**: (1, 0, 0)

### Local Transform

$$
T^{3}_{5}(q_{5}) = \begin{bmatrix}
1 & 0 & 0 & 0 \\
0 & c_{5} & -s_{5} & 0.155835 \\
0 & s_{5} & c_{5} & -0.126947 \\
0 & 0 & 0 & 1 \\
\end{bmatrix}
$$

---

## wheel_left

$L_{5}$ **link3_left** -> $L_{6}$ **wheel_left** (continuous)
  Variable: $q_{6}$

- **origin xyz**: (-0.303192, 0.024704, -0.014133) m
- **origin rpy**: (3.141593, 0, -1.570796) rad
- **axis**: (-0.309017, 0, -0.951057)

### Local Transform

$T^{5}_{6}(q_{6}) = T_{fixed} \cdot R_{axis}(q_{6})$ where:

$$
T_{fixed} = \begin{bmatrix}
0 & -1 & 0 & -0.303192 \\
-1 & 0 & 0 & 0.024704 \\
0 & 0 & -1 & -0.014133 \\
0 & 0 & 0 & 1 \\
\end{bmatrix}
$$

$$
R_{axis}(q_{6}) = \begin{bmatrix}
c_{6} & s_{6} & 0 & 0 \\
-s_{6} & c_{6} & 0 & 0 \\
0 & 0 & 1 & 0 \\
0 & 0 & 0 & 1 \\
\end{bmatrix}
$$

---

## Global Transform Chains

Transform from root $L_0$ to any link, as product of local transforms along the kinematic chain.

$$T^{0}_{2} = T^{0}_{1}(q_{1}) \cdot T^{1}_{2}(q_{2})\quad (L_0 \to L_{2}: \text{link3_right})$$

$$T^{0}_{3} = T^{0}_{1}(q_{1}) \cdot T^{1}_{3}(q_{3})\quad (L_0 \to L_{3}: \text{link1_left})$$

$$T^{0}_{4} = T^{0}_{1}(q_{1}) \cdot T^{1}_{2}(q_{2}) \cdot T^{2}_{4}(q_{4})\quad (L_0 \to L_{4}: \text{wheel_right})$$

$$T^{0}_{5} = T^{0}_{1}(q_{1}) \cdot T^{1}_{3}(q_{3}) \cdot T^{3}_{5}(q_{5})\quad (L_0 \to L_{5}: \text{link3_left})$$

$$T^{0}_{6} = T^{0}_{1}(q_{1}) \cdot T^{1}_{3}(q_{3}) \cdot T^{3}_{5}(q_{5}) \cdot T^{5}_{6}(q_{6})\quad (L_0 \to L_{6}: \text{wheel_left})$$

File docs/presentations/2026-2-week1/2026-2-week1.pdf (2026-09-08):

# 캡스톤 디자인

## 2026 CAPSTONE DESIGN PRESENTATION


# 2 학기 하드웨어 제작 , 설계 및 시뮬레이션 결과 보고

Project by. 2 조 2021121173
정성훈 | Date. 2026.09.07


02 | 링크부 체결 | 06p
03 | Hardware Design & Assembly | 08p
| ● Supporter Desgin ● Assembly Video
04 | 모터 구동영상 및 설명 | 10p
| ● 서보모터 구동 ● 인휠모터 구동
05 | 하드웨어 제작 계획 | 31p
| ● 3D printing

# CONTENTS

## 목차 보기

01 | MATLAB Simulink | 03p
| ● 스쿼트 모션 영상 및 피치 스코프 ● 주행 영상 및 피치 스코프 ● 주행 + 스쿼트 모션 영상 및 피치 스코프
| ● MisuMi 사 부시 및 샤프트를 이용하여 결합 ● 각 링크별 부시의 필요한 최소길이

01 | Matlab 시뮬레이션 ● 스쿼트 모션 영상 및 피치 스코프


스쿼트 모션 영상 | pitch scope

# MATLAB SIMULINK

# MATLAB SIMULINK


01 | Matlab 시뮬레이션 주행 영상 및 피치 스코프
주행 영상 | pitch scope

# MATLAB SIMULINK


01 Matlab 시뮬레이션 주행 + 스쿼트 모션 영상 및 피치 스코프

## 주행 + 스쿼트 모션

영상

pitch scope

## MisuMi 사 부시 및 샤프트를 이용하여

# 링크부 체결


02
결합
- 부시와 샤프트를 체결하여 결합

https://kr.misumi-ec.com/vona2/detail/110300027150/?list=PageCategory - 리니어 부시 https://kr.misumi-ec.com/vona2/detail/110310559889/?clkid=clkid_pdct_kr_ec_45189_105 -
샤프트
플랜지붙이 리니어부시 | 리니어 샤프트

## 부시 , 샤프트

체결

미스미 (Misumi) 는 산업용 기계 부품 분야에서 높은 신뢰도와 인지도를 가진 매우 유명한 일본계 기업

# 링크부 체결


02 | MisuMi 사 부시 및 샤프트를 이용하여 결합 ● 각 링크별 부시의 필요한 최소길이
뒷 허벅지와 토르소 사이 | 허벅지와 무릎 사이 | 뒷 허벅지와 무릎 사이

03 Supporter Desgin ● Supporter 를 통한 토르소 및 센서 보호

# HARDWARE DESIGN & ASSEMBLY

Supporter 디자인 | Supporter 설계 이유

## 서포터와 하우징 프레임이 외력을 대신

지지하여 축의 직접적인 파손을 방지합니다 .

# ASSEMBLY VIDEO


## 04 서보모터 구동

# 모터 구동영상



## 04 인휠모터 구동

# 모터 구동영상

# 하드웨어 제작 계획


05 | 3D printing ● 교내 시설 ( 드론앵커센터 or 기게공작실 ) 이용 예정
드론앵커센터 | Ultimaker S5 Pro 3D printer | Markforged Mark 2 3D printer 실

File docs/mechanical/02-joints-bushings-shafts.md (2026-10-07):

# 02 — 링크 조인트: 부시 · 샤프트 · 체결 설계

## 0. 조인트 정의 (설계 자세, 고관절 원점)

| 조인트 | 위치 (Y, Z) mm | 연결 |
|---|---|---|
| **A** | (114, 49) | 토르소 ↔ 보조링크 |
| **KNEE** | (174, −164) | 허벅지 ↔ 종아리 |
| **B** | (228.5, −128.6) | 보조링크 ↔ 종아리 |

## 1. "그냥 나사만 박으면 자유도가 나오나" — 회전은 됩니다. 다만 4가지가 걸립니다

자유도 자체는 정상입니다. 고관절은 하우징(고정) ↔ 출력(회전) 1자유도이고, 허브 축이 토르소
Ø43 보어를 3.5 mm 여유로 통과하므로 어디에도 물리지 않습니다.
문제는 "돌아가느냐"가 아니라 **"얼마나 버티고 얼마나 흔들리느냐"** 입니다.

### 1-1. 체결부 마찰 전달 여유 (K = 0.20, μ = 0.15)

> ⚠️ 아래 허브/마운트링 행은 **AK45 플랜지(6-M3 PCD27 / PCD48), 피크 24 N·m** 기준입니다.
> DM4340P(피크 27 N·m) 로 바뀌면서 플랜지 패턴이 달라지므로 재검토 필요 — [05 §4](05-hip-actuator-DM4340P.md).
> 허브↔허벅지(8-M4 PCD60)는 27 N·m 에서도 안전율 ≈ 5.0 으로 유지됩니다.

| 체결부 | 볼트 | PCD | 전달토크 | 요구 접선력 | 조임 | 예압 | 마찰용량 | **안전율** |
|---|---|---|---|---|---|---|---|---|
| 허브 ↔ AK45 출력 | 6-M3 | 27 | 24 N·m | 1778 N | 1.3 N·m | 2167 N | 1950 N | **1.10 ★** |
| 마운트링 ↔ AK45 | 6-M3 | 48 | 24 N·m | 1000 N | 1.3 N·m | 2167 N | 1950 N | 1.95 |
| 허브 ↔ 허벅지 | 8-M4 | 60 | 24 N·m | 800 N | 3.0 N·m | 3750 N | 4500 N | 5.62 |

**★ 허브 ↔ 출력은 나사 마찰만으로 안전율 1.10 — 미끄러집니다.**
→ **Ø18 h7 스피곳 + 3 × Ø4 다웰핀 필수.** 다웰 3개(PCD22)면 전단허용 200 MPa 기준
**82.9 N·m** 를 받습니다. 나사는 축력만, 토크는 다웰이 받는 구조. (CAD 반영 완료)

### 1-2. PLA 에 직접 탭은 안 됩니다

| 방식 | 안전 예압 | 6개 마찰용량 | 요구 800 N | 판정 |
|---|---|---|---|---|
| PLA 직접탭 M4×8 | 419 N | 377 N | 800 N | **안전율 0.47 — 불가** |
| 황동 열간삽입 인서트 M4 | 900 N | 810 N | 800 N | 1.01 — 확보 |

### 1-3. M6 볼트 머리가 PLA 를 눌러 찌그러뜨립니다

| 조건 | 예압 | 접촉면적 | 압축응력 | 판정 |
|---|---|---|---|---|
| M6 소켓헤드 단독, 10 N·m | 8333 N | 44 mm² | **188 MPa** | PLA 파손 |
| M6 소켓헤드 단독, 4 N·m | 3333 N | 44 mm² | **75 MPa** | PLA 파손 |
| **Ø18 대형와셔, 4 N·m** | 3333 N | 220 mm² | **15 MPa** | OK (허용 ~40) |
| Ø18 대형와셔, 6 N·m | 5000 N | 220 mm² | 23 MPa | OK, 마찰 안전율 4.15 |

→ **종아리 ↔ 휠 M6 4개는 Ø18 대형와셔 + 조임토크 4~6 N·m 로 제한.**

### 1-4. 고관절이 캔틸레버입니다

| 항목 | 값 |
|---|---|
| AK45 출력베어링 X ≈ ∓142, 휠 접지 X ≈ ∓258 | **편심 116 mm** |
| 정지 시 전도모멘트 | **6.54 N·m** (24 %) |
| 주행 요철 (2G) | 13.07 N·m (47 %) |
| 착지 (3G) | **19.61 N·m** (71 %) |
| AK45 출력베어링 모멘트 정격 (C₀ 2760 N, 유효 Ø40 추정) | ≈ **27.6 N·m** |
| DM4340P 출력베어링 | **크로스 롤러 베어링** — 모멘트 정격은 제조사 도면 확인 필요 (일반적으로 같은 크기 볼베어링보다 유리) |
| 백래시 12 arcmin → 힙~휠 336 mm 지점 유격 | **±1.17 mm** |

버티긴 하지만 여유가 적고, 백래시 ±1.17 mm 가 그대로 다리 흔들림 → 밸런싱 제어의 데드존입니다.

## 2. 조인트별 구현

### 2-1. A — 토르소 ↔ 보조링크

기존: 토르소 Ø17 관통구(벽 10), 커플러 Ø14 부시 보어(16), 부시 Ø12/Ø14 L15 플랜지 Ø20.

**`40_SHAFT_A_D17-D12_L27`** (단차 샤프트)
- Ø17 h7 × 10 → 토르소 벽 삽입 (X ∓144…∓154)
- Ø12 g6 × 17 → 커플러 부시 관통 (X ∓154…∓171)
- **양단 M5 암나사 × 10 dp**

체결: 아웃보드 `50_FIX_M5_W18` (M5×12 + Ø18 와셔)로 부시 플랜지 압착 /
인보드 `51_FIX_M5_W30` (M5×10 + Ø30 와셔)로 토르소 안쪽에서 이탈 방지. **신규 구멍 없음.**

### 2-2. KNEE — 허벅지 ↔ 종아리

**볼베어링(6904ZZ ×2)을 그대로 씁니다.** Ø20 축에 맞는 오일리스 부시는 OD 26~28 이 표준인데
종아리 보어는 Ø37 — 6904 전용 치수입니다. 하중이 가장 큰 관절이라 볼베어링이 유리합니다.

**`41_SHAFT_KNEE_D20_L56`** : Ø20 h7 × 56 (X ∓173…∓229), 양단 M6 암나사 × 12 dp

체결:
- 아웃보드 `52_FIX_M6_W26` (M6×14 + **Ø26 와셔**) — Ø26 이면 외륜(Ø31.7)에 닿지 않아 베어링이 잠기지 않음
- 인보드 `53_FIX_M6_W30` (M6×14 + Ø30 와셔)
- **신규**: 허벅지 무릎 보스에 M4 세트스크루 반경방향 탭 (샤프트 회전방지)
- **신규**: 종아리 Ø20 구간(X ∓201…∓211)을 **Ø22 로 릴리프** — 샤프트와 PLA 마찰 방지

### 2-3. B — 보조링크 ↔ 종아리

원본 모델의 오류 2건을 수정했습니다.
1. 종아리에 일체형 **Ø13 PLA 핀**이 나와 있었는데 부시 내경이 Ø12 라 **1 mm 간섭**
2. 부시 플랜지 Ø20 이 종아리 Ø32 보스와 **160 mm³ 간섭**

조치: Ø13 핀 제거 → **Ø12 H7 × 21.5 보어** 신설 → 보스 단면에 **Ø21 × 1.3 카운터보어**
→ **`42_SHAFT_B_D12_L37`** (Ø12 g6 × 37, 인보드단 M5 탭) + `50_FIX_M5_W18`
+ 종아리 보스에 M4 세트스크루 탭

## 3. MISUMI 부품 — ⚠ 선택하신 품번은 회전에 쓰면 안 됩니다

[110300027150 — 플랜지붙이 리니어부시 표준 더블형](https://kr.misumi-ec.com/vona2/detail/110300027150/)
은 **볼 리니어부시(LM 부시)** 로 **직선 왕복 전용**입니다. 볼이 축방향 궤도를 순환하는 구조라
회전시키면 볼이 궤도 벽면을 압흔(brinelling)시켜 수 시간 만에 유격이 생기고 파손됩니다.
TWLR 의 3개 조인트는 전부 **요동(oscillating) 회전**입니다.

### 대체 추천

| 순위 | 품목 | 링크 | 비고 |
|---|---|---|---|
| **1** | 오일리스 부시 플랜지붙이 **MPFZ** (고장력 황동 + 고체윤활제) | [110302579350](https://in.misumi-ec.com/vona2/detail/110302579350/) | 회전·요동 모두 가능, 무급유. 축 공차 g6 |
| 2 | OILES 글라이트론SE 플랜지 부시 **GSF** | [221000090857](https://kr.misumi-ec.com/vona2/detail/221000090857/?HissuCode=GSF-082207) | 수지계, 가볍고 저마찰 |
| 3 | **DU 부시** (PTFE 라이닝, 강 백킹) Ø12/Ø14 벽두께 1 | 표준 사이즈 | **현재 CAD 의 iglidur JSM-1214 와 동일 치수 — 보어 수정 없이 교체 가능** |

> MPFZ12 는 표준 벽두께가 3 mm(OD 18) 급이라 커플러 Ø14 보어를 Ø18 로 넓혀야 합니다.
> 보어를 안 건드리려면 **DU 부시 12×14×15 플랜지형**이 정답입니다.

**샤프트**는 [리니어 샤프트](https://kr.misumi-ec.com/vona2/detail/110310559889/) 계열이 맞되
**양단 암나사 타입(SFJ / PSFJ)** 을 고르세요. 위 설계는 전부 "샤프트 양단 탭 + 스크루 + 와셔"로
축방향을 잡는 구조라, 암나사가 없으면 스냅링 홈을 따로 파야 합니다.

| 조인트 | 샤프트 | 부시 |
|---|---|---|
| A | Ø12 g6, 전장 27 (Ø17 단차 10 포함), 양단 M5 | Ø12/Ø14 L15 플랜지 |
| KNEE | Ø20 h7, 전장 56, 양단 M6 | 6904ZZ × 2 |
| B | Ø12 g6, 전장 37, 편단 M5 | Ø12/Ø14 L15 플랜지 |

### 부시 최소 길이

| 조인트 | 하중 (3G) | 축경 | 필요 L (허용 면압 20 MPa) | 현재 L15 |
|---|---|---|---|---|
| A | ≈ 250 N | 12 | 1.0 mm | 충분 (15배) |
| B | ≈ 250 N | 12 | 1.0 mm | 충분 |
| KNEE | ≈ 560 N | 20 | 볼베어링, 정격 6.37 kN | 충분 |

면압은 전혀 문제가 아니고, 길이는 **기울어짐(미스얼라인) 방지** 기준으로 잡아야 합니다.
L/d ≥ 1.0 이 통상 기준인데 A·B 는 15/12 = 1.25 ✓

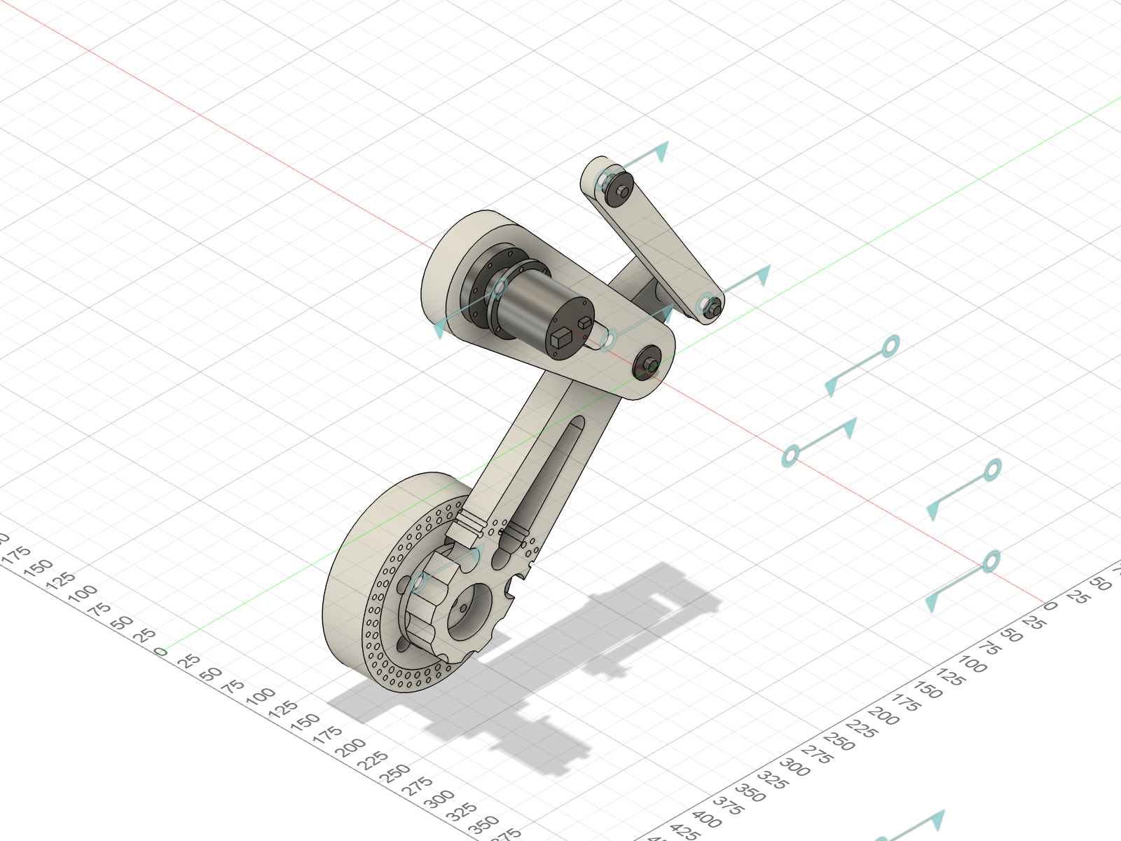
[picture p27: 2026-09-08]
hardware/images/leg_left_iso.png

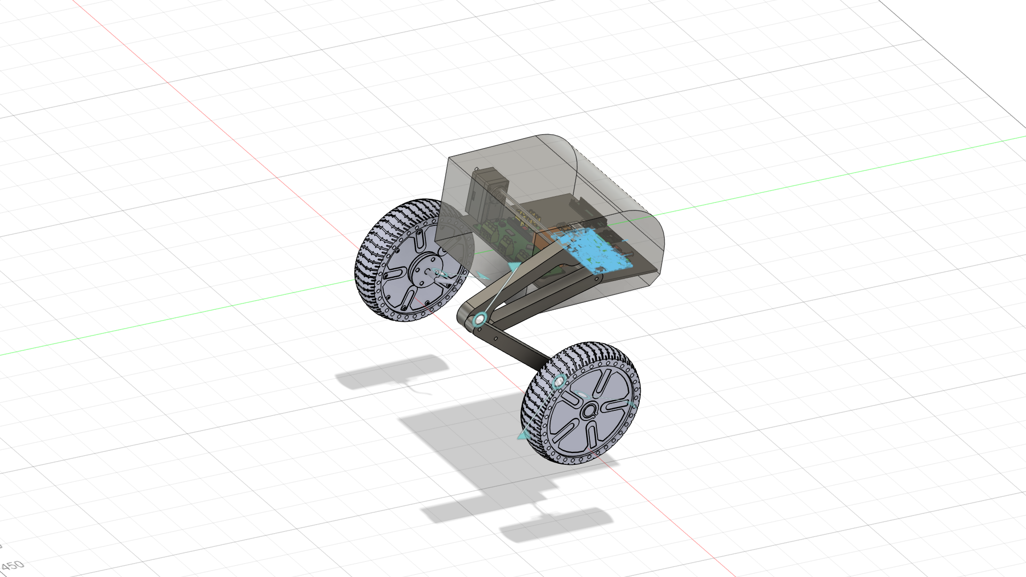
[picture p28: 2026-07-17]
images/robot.png

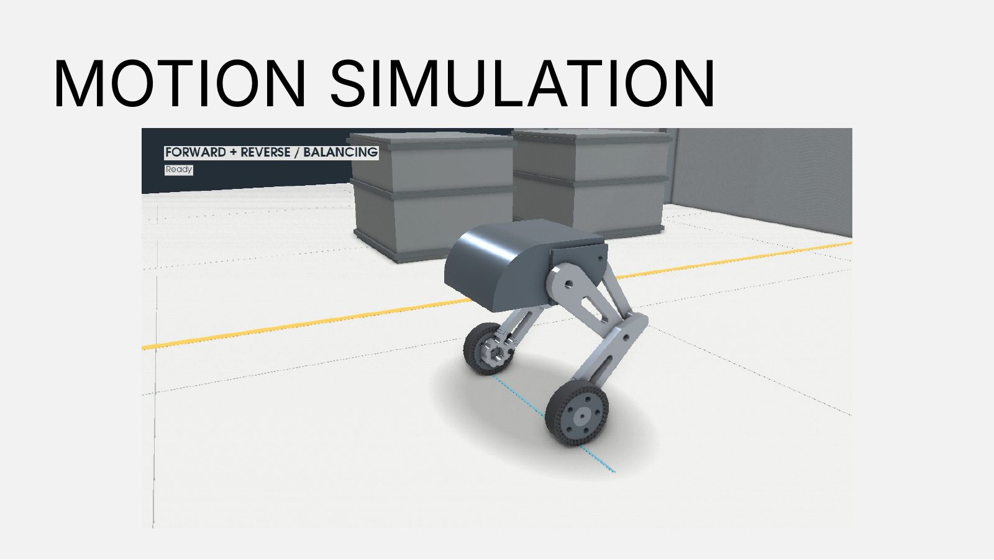
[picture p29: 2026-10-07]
docs/presentations/2026-2-week2/slides/slide-07.jpg

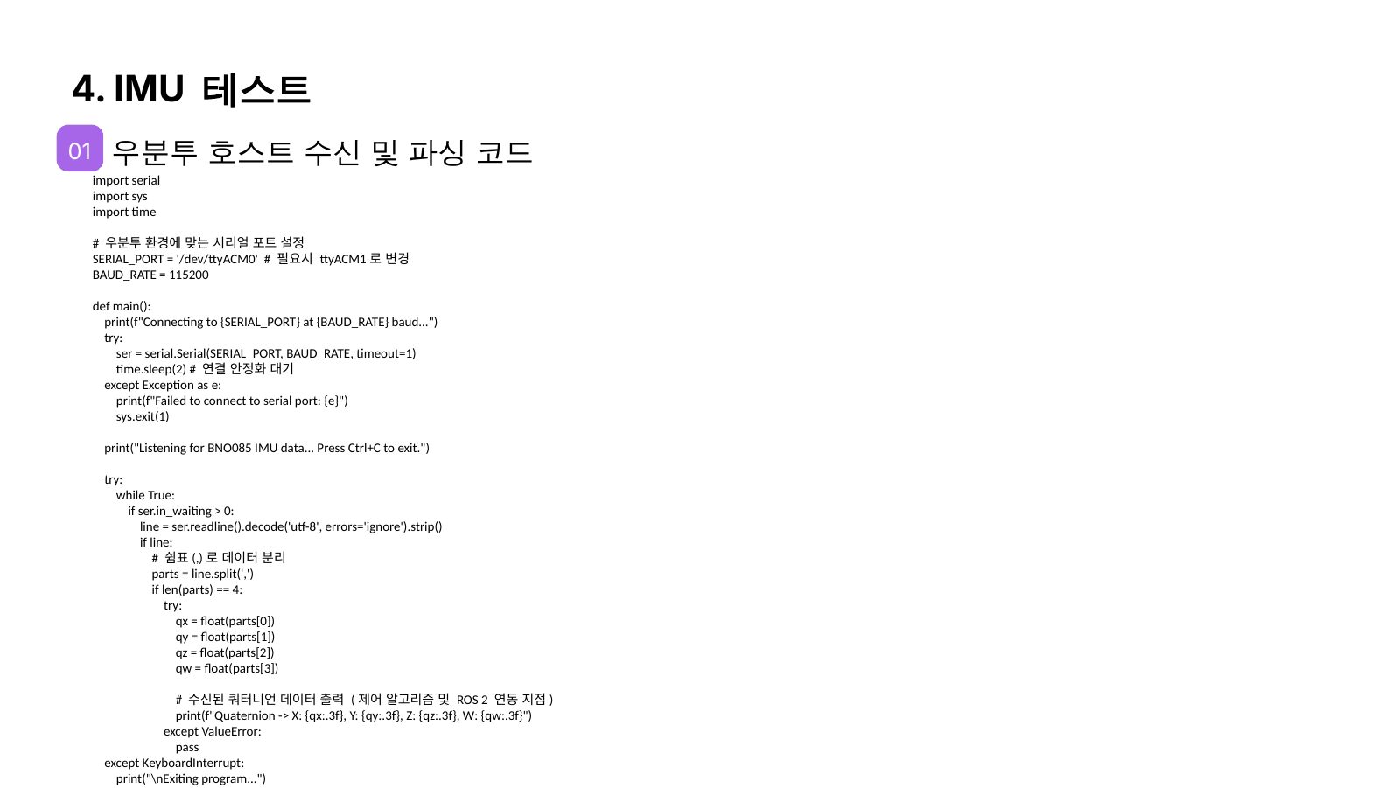
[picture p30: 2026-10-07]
docs/presentations/2026-2-week3/slides/slide-22.jpg

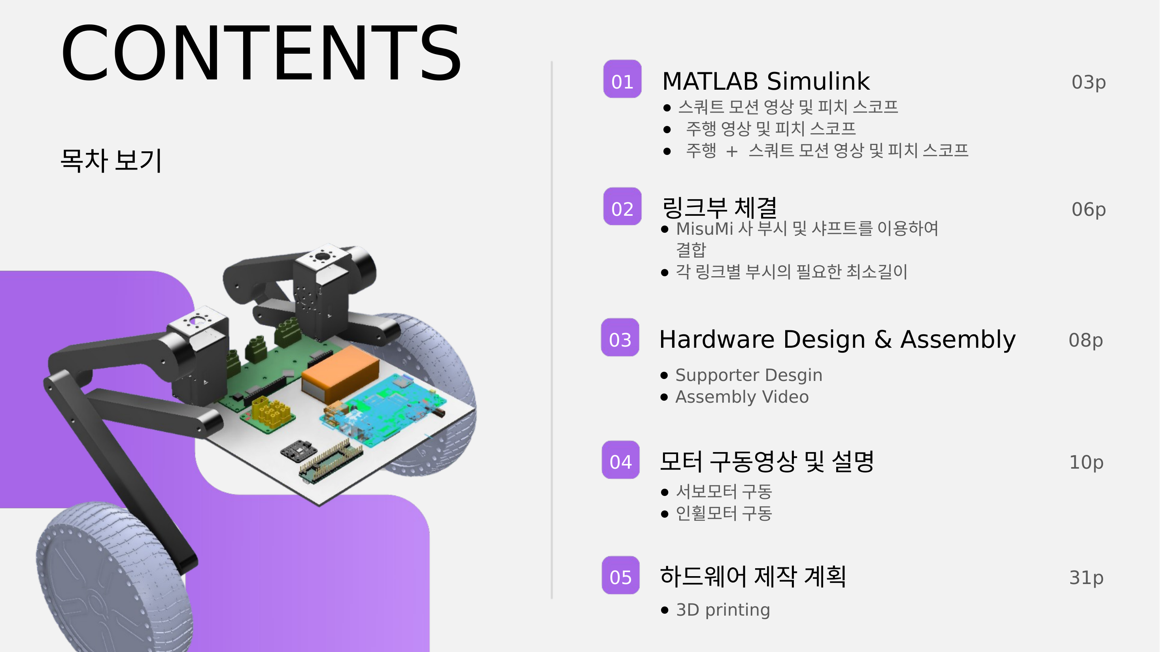
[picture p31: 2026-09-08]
docs/presentations/2026-2-week1/slides/slide-02.png

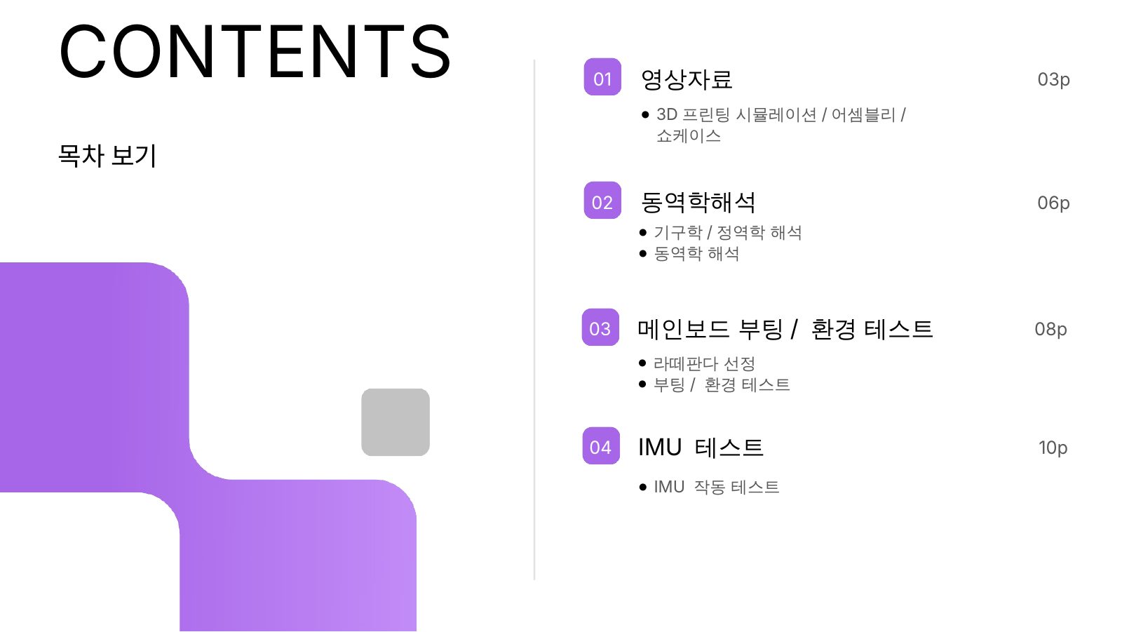
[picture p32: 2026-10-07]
docs/presentations/2026-2-week3/slides/slide-02.jpg

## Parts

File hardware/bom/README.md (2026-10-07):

# TWLR 구매 BOM

원본: [`TWLR_BOM.xlsx`](TWLR_BOM.xlsx) (팀 공유 시트, 2026-10 기준). `가격` 열은 해당 수량의 소계입니다.
`부족분 = max(수량 − 구매, 0)` 수식이 들어 있습니다.

## 구매품

| 품목 | 수량 | 구매처 | 가격(원) | 비고 |
|---|---:|---|---:|---|
| **서보모터 Damiao DM4340P** (DM-J4340P-2EC, 40:1) | 2 | 디바이스마트 | 635,200 | 고관절. AK45-36 배송 지연으로 교체 → [05](../../docs/mechanical/05-hip-actuator-DM4340P.md) |
| 누리로봇 인휠모터 | 2 | 로봇코트 | 154,000 | 구동 휠 (구매 1) |
| VEGA 그래핀 6셀 22.2 V 5200 mAh 배터리 | 1 | 디바이스마트 | 100,200 | 6S |
| Teensy 4.1 | 1 | 디바이스마트 | 67,500 | 하위 제어기 (IMU · CAN) |
| CAN 트랜시버 | 3 | 디바이스마트 | 27,000 | Teensy ↔ DM4340P |
| 24 V → 5 V 강압기 | 1 | 쿠팡 | 14,530 | |
| XT90 배터리 커넥터 | 1 | 디바이스마트 | 3,600 | |
| 원터치 전선연결 커넥터 221-415 (5핀) | 2 | 디바이스마트 | 1,800 | |
| 리니어부시 C-LHFR8 | 6 | 미스미 | 36,023 | VAT 포함 소계 |
| 리니어부시 C-LHFR13 | 2 | 미스미 | 12,894 | VAT 포함 소계 |
| 샤프트 PSFGW13-68-M6-N6 | 1 | 미스미 | 5,808 | VAT 포함 소계 |
| 샤프트 PSFGW8-54-M3-N3 | 1 | 미스미 | 15,912 | VAT 포함 소계 |
| 샤프트 PSFGW8-38-M3-N3 | 2 | 미스미 | 28,338 | VAT 포함 소계 |
| M3 볼트 5 cm (30개입) | 1 | 쿠팡 | 6,900 | |
| M3 볼트 25 mm | 1 | 쿠팡 | 7,300 | |
| 3.5 mm 나사 (부싱 결합용) | 1 | 쿠팡 | 4,600 | |
| 4.5 mm 나사 (부싱 결합용) | 1 | 쿠팡 | 4,800 | |
| 드레멜 | 1 | 네이버스토어 | 58,390 | 공구 |
| **총계** | | | **1,184,795** | 시트의 `SUM(F2:F19)` |

## 3D 프린팅 & 메모

| 항목 | 수량 | 구매처 | 가격(원) | 비고 |
|---|---:|---|---:|---|
| 다리 링크 한 쪽 & 본체 판 2개 | 1 | 드론앵커센터 | 150,000 | 3D 프린팅 (총계 별도) |
| 루빅 링크 V3 | 1 | 아트콥터 | 37,400 | **서보모터 변경으로 제외** |

> 2주차 발표 기준 링크부 출력은 고양시 드론앵커센터, 비용 84,000원.
> 토르소 본체(`UM S5_body_2`)는 Cura 슬라이싱 기준 **23시간 42분 / 476 g / 필라멘트 60.18 m**
> ([출력 시뮬레이션 영상](../media/torso-print-sim-cura.mp4)).

### 부시 관련 주의
`C-LHFR` 는 볼 리니어부시 계열로 **직선 왕복용**입니다. A·KNEE·B 조인트는 요동 회전이므로
장기적으로 볼 압흔에 의한 유격이 생길 수 있습니다 → [02 §3](../../docs/mechanical/02-joints-bushings-shafts.md).

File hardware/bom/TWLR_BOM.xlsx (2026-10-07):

이름 | 수량 | 구매 | 부족분 | 구매사이트 | 가격 | 비고
누리로봇 인휠모터 | 2 | 1 | 1 | 로봇코트 (https://robotcourt.com/product/%EB%88%84%EB%A6%AC%EB%A1%9C%EB%B4%87-%EC%9D%B8%ED%9C%A0%EB%AA%A8%ED%84%B0-%EC%97%94%EC%BD%94%EB%8D%94-wa172e/141/category/66/di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) | 154000
VEGA 베가 그래핀 6셀 22.2V 5200mAh 배터리 | 1 | 0 | 1 | 디바이스마트 (https://www.devicemart.co.kr/goods/view?no=16033675) | 100200
원터치 전선연결 커넥터 221-415 (5핀) | 2 | 0 | 2 | 디바이스마트 (https://www.devicemart.co.kr/goods/view?no=10827023) | 1800
XT90 배터리 커넥터 | 1 | 0 | 1 | 디바이스마트 (https://www.devicemart.co.kr/goods/view?no=15960461) | 3600
M3 볼트 5cm(30개입) | 1 | 0 | 1 | 쿠팡 (https://www.coupang.com/vp/products/9358209465?itemId=27765190695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) | 6900
24V -> 5V 강압기 | 1 | 0 | 1 | 쿠팡 (https://www.coupang.com/vp/products/7048461479?itemId=17447938051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) | 14530
CAN 트랜시버 | 3 | 0 | 3 | 디바이스마트 (https://www.devicemart.co.kr/goods/view?no=15007385) | 27000
Teensy4.1 | 1 | 0 | 1 | 디바이스마트 (https://www.devicemart.co.kr/goods/view?no=14276922) | 67500
드레멜 | 1 | 0 | 1 | 네이버스토어 (https://smartstore.naver.com/kwshop/products/11630733328?nl-ts-pid=jrZNudqX5EwssBAvnrG-240565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) | 58390
3.5MM 나사(부싱 결합용) | 1 | 0 | 1 | 쿠팡 (https://www.coupang.com/vp/products/8421487746?itemId=24358638683&vendorItemId=91373991498&searc) | 4600
4.5MM 나사(부싱 결합용) | 1 | 0 | 1 | 쿠팡 (https://www.coupang.com/vp/products/8421487742?itemId=24358638675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) | 4800
M3 볼트 25mm | 1 | 0 | 1 | 쿠팡 (https://www.coupang.com/vp/products/9485327739?itemId=28482319850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) | 7300
리니어부시(C-LHFR8) | 6 | 0 | 6 | 미즈미 (https://kr.misumi-ec.com/?srsltid=AU7gw4XHaJzvjUpkMQ8GEZGD7fnjMk8RLwXBBV-jmT8HMEKLjUv7-OQA) | 36023 | (VAT포함소계)
리니어부시(C-LHFR13) | 2 | 0 | 2 | 미즈미 (https://kr.misumi-ec.com/?srsltid=AU7gw4XHaJzvjUpkMQ8GEZGD7fnjMk8RLwXBBV-jmT8HMEKLjUv7-OQA) | 12894 | (VAT포함소계)
샤프트(PSFGW13-68-M6-N6) | 1 | 0 | 1 | 미즈미 | 5808 | (VAT포함소계)
샤프트(PSFGW8-54-M3-N3) | 1 | 0 | 1 | 미즈미 | 15912 | (VAT포함소계)
샤프트(PSFGW8-38-M3-N3) | 2 | 0 | 2 | 미즈미 (https://kr.misumi-ec.com/?srsltid=AU7gw4XHaJzvjUpkMQ8GEZGD7fnjMk8RLwXBBV-jmT8HMEKLjUv7-OQA) | 28338 | (VAT포함소계)
서보모터 (Damiao DM4340P) | 2 | 0 | 2 | 디바이스마트 (https://www.devicemart.co.kr/goods/view?no=16019401) | 635200
 |  |  |  | 총계 | 1184795
3D 프린팅 & 메모용
다리 링크 한 쪽 & 본채 판 2개 | 1 | 0 | 1 | 드론앵커센터 | 150000 | 3D 프린팅(별도)
루빅 링크 V3 | 1 | 0 | 1 | 아트콥터 (https://artcopter.com/product/cubemars-rubik-link-%EB%A3%A8%EB%B9%85-%EB%A7%81%ED%81%AC-v3/1162/category/439/display/1/) | 37400 | 서보모터 변경으로 제외

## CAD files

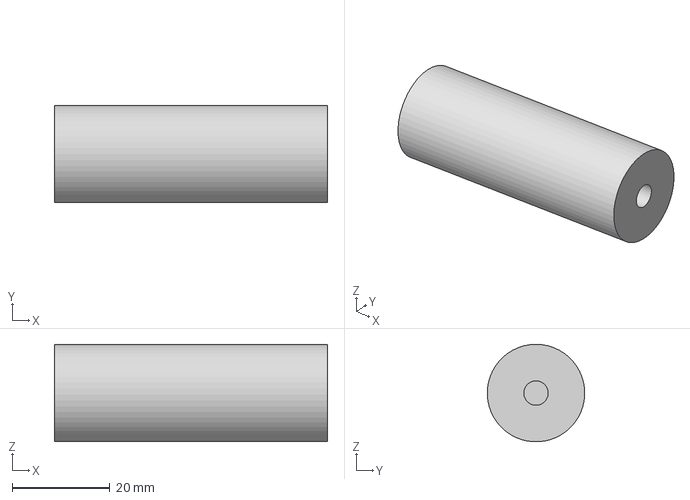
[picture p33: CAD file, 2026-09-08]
hardware/cad/step/41_SHAFT_KNEE_D20_L56.step
56.0 x 20.0 x 20.0 mm

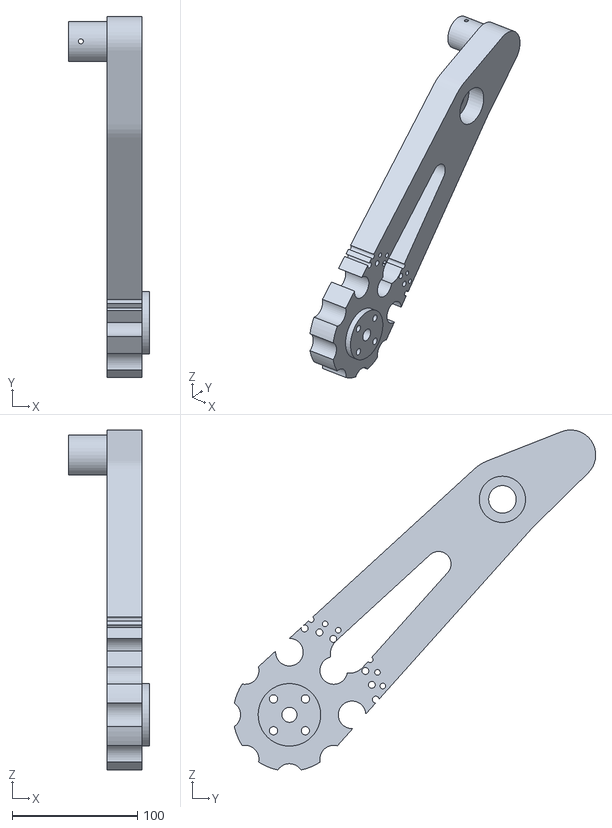
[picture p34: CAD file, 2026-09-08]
hardware/print/as-designed/09_Shin_R.stl
65.0 x 288.5 x 271.4

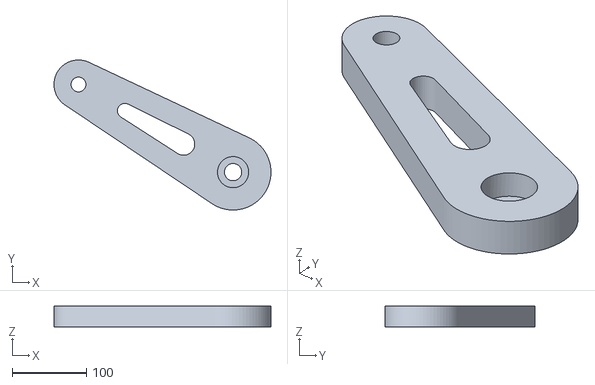
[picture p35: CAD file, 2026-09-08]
hardware/print/print-ready/06_Thigh_L_PRINT.stl
291.9 x 201.9 x 28.0

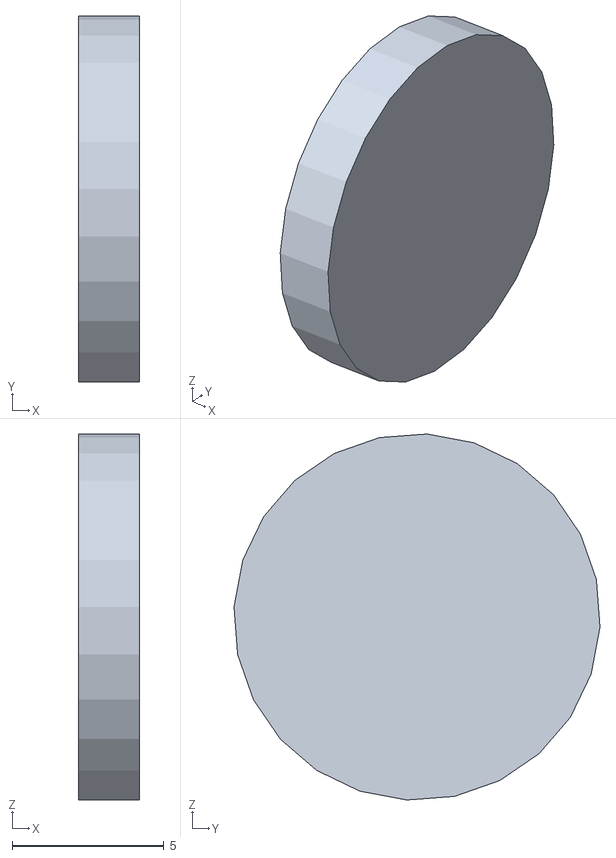
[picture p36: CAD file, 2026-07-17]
meshes/TWLR/link3_left_collision.stl
2.00 x 12.1 x 12.1

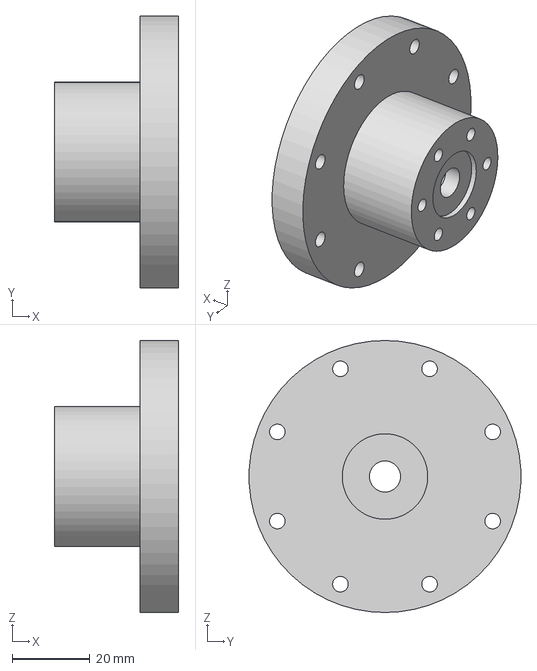
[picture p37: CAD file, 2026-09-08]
hardware/cad/step/21_HUB_Hip_Output.step
32.0 x 69.9 x 70.0 mm

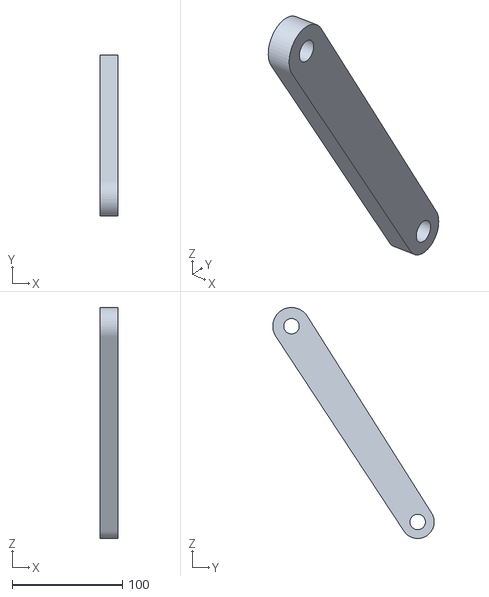
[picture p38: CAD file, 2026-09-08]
hardware/print/as-designed/03_Coupler_R.stl
16.0 x 146.5 x 209.6

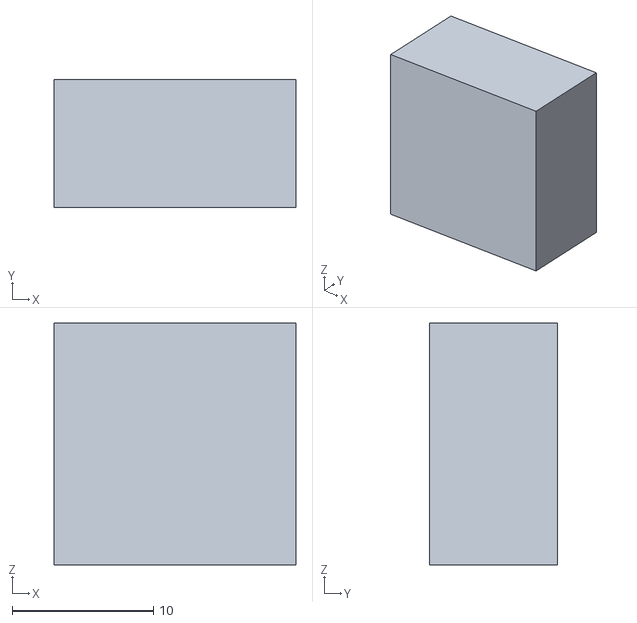
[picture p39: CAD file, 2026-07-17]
meshes/TWLR/wheel_right_collision.stl
17.1 x 9.08 x 17.1

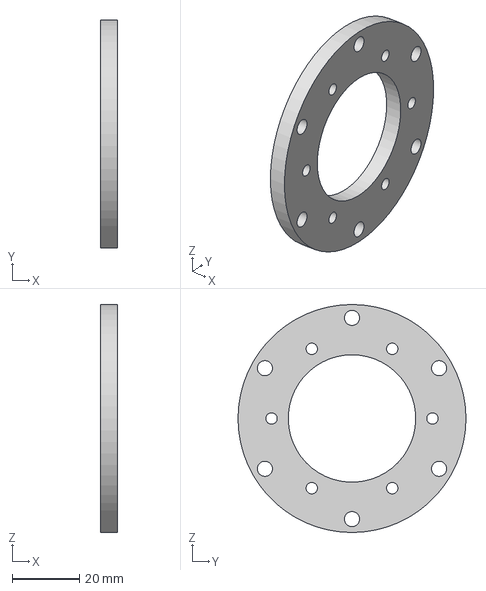
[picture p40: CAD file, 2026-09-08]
hardware/cad/step/22_MNT_AK45_Ring.step
5.00 x 68.0 x 68.0 mm

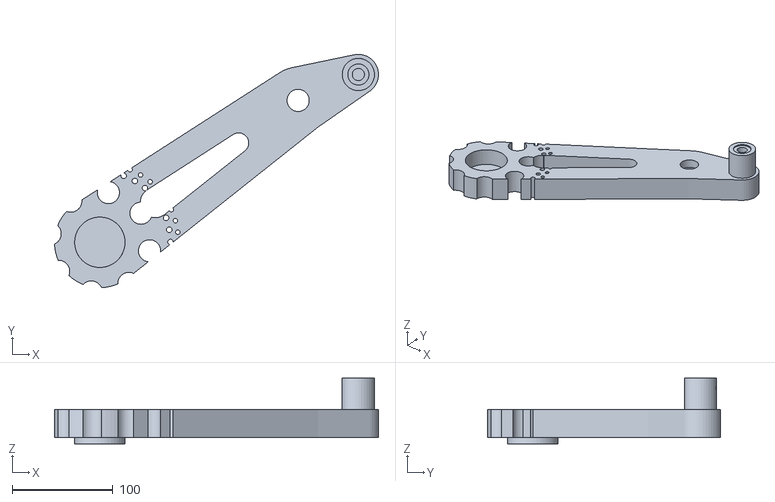
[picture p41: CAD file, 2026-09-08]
hardware/print/print-ready/07_Shin_L_PRINT.stl
321.3 x 231.3 x 65.0

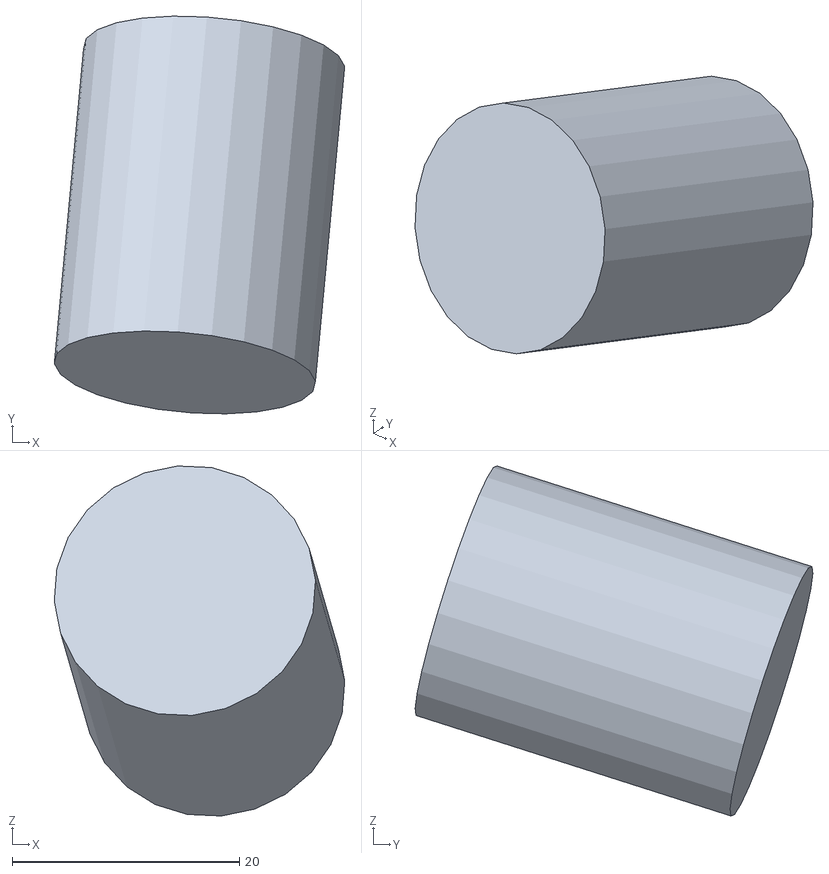
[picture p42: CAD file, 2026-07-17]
meshes/TWLR/base_link_collision.stl
25.6 x 35.0 x 30.8

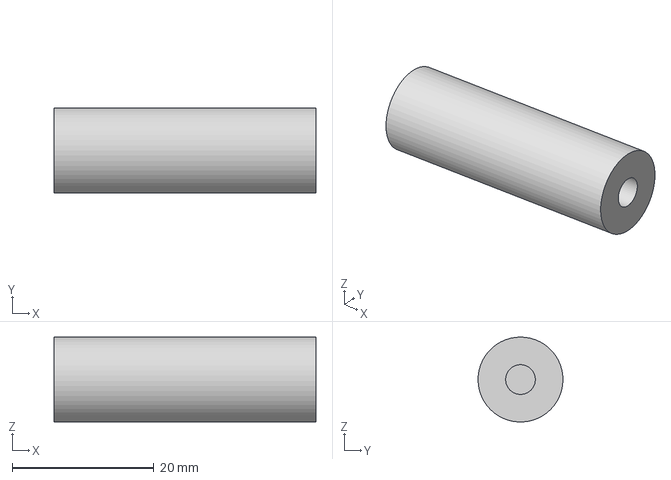
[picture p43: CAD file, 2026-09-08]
hardware/cad/step/42_SHAFT_B_D12_L37.step
37.0 x 12.0 x 12.0 mm

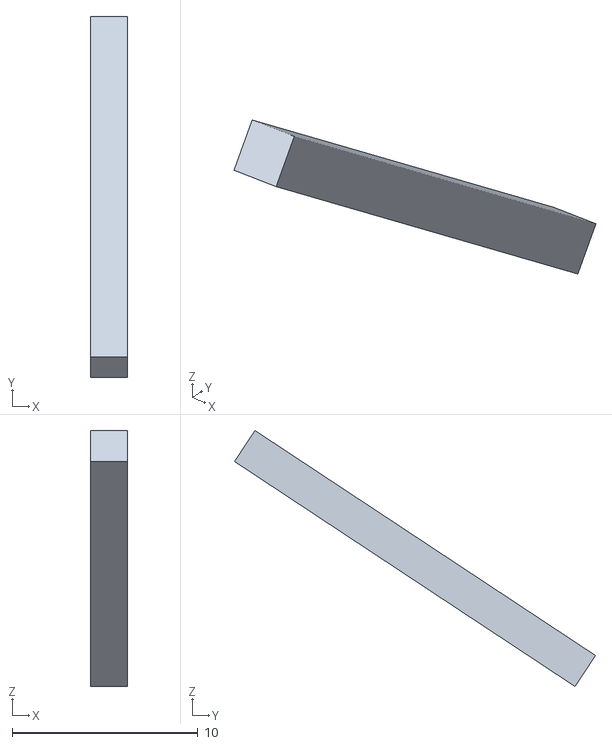
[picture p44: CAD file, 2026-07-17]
meshes/TWLR/link1_left_collision.stl
2.00 x 19.5 x 13.8

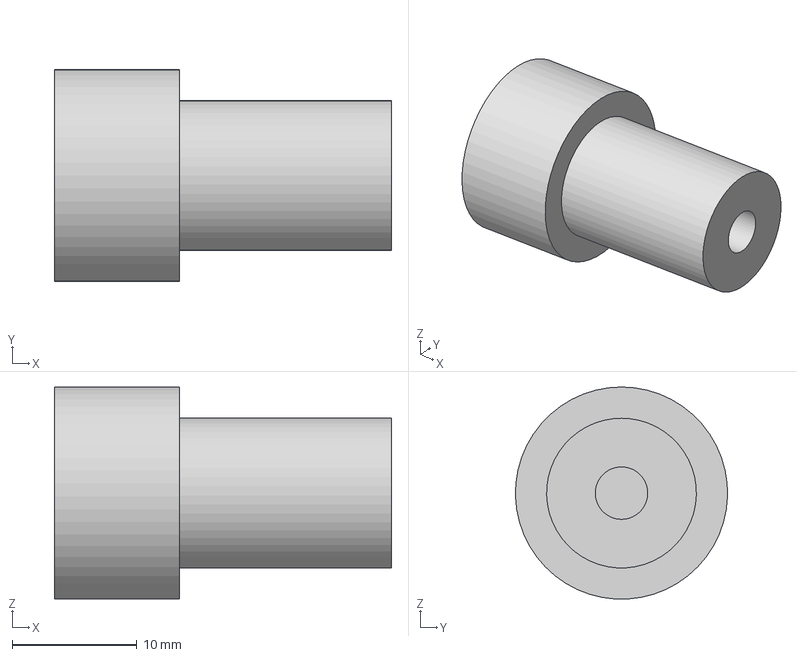
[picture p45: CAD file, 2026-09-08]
hardware/cad/step/40_SHAFT_A_D17-D12_L27.step
27.0 x 17.0 x 17.0 mm

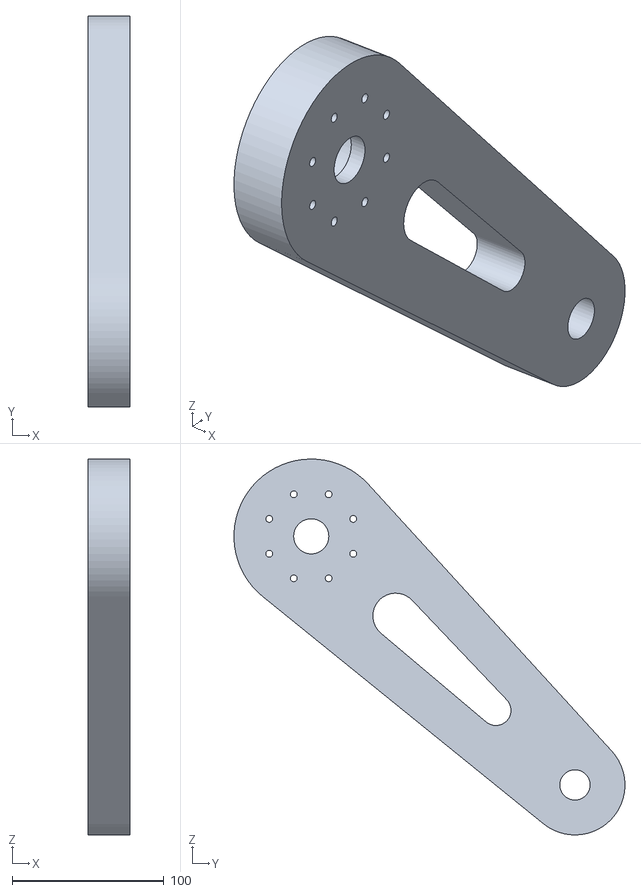
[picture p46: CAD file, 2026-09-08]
hardware/print/as-designed/08_Thigh_R.stl
28.0 x 258.0 x 248.0

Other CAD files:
hardware/print/print-ready/08_Thigh_R_PRINT.stl
hardware/print/as-designed/02_Coupler_L.stl
hardware/print/as-designed/07_Shin_L.stl
hardware/print/print-ready/09_Shin_R_PRINT.stl
hardware/cad/TWLR_assembly_AK45.f3d
hardware/print/as-designed/06_Thigh_L.stl
hardware/print/print-ready/02_Coupler_L_PRINT.stl
hardware/print/print-ready/03_Coupler_R_PRINT.stl
meshes/TWLR/link1_right_collision.stl
meshes/TWLR/link3_right_collision.stl
meshes/TWLR/wheel_left_collision.stl

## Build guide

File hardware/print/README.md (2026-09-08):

# 3D 프린팅 가이드

## 어떤 파일을 쓰나

| 폴더 | 내용 |
|---|---|
| **`print-ready/`** | **이것을 쓰세요.** 나사구멍 제거 + 눕힘 + 베드 최적 회전 + Z=0 안착. 슬라이서에 그대로 |
| `as-designed/` | 설계 그대로 (나사구멍 포함). 참고/검증용 |

`print-ready` 는 `as-designed` 와 체적 오차 **0.0000 %** 로 검증됨 (회전만 적용).

### 제거된 구멍 (직접 가공)
8 × Ø4.5 PCD60(허브), 무릎 M4 세트스크루, 4 × Ø6.6 PCD36 + Ø12 중심홀(휠), B 조인트 M4 세트스크루

### 유지된 보어 (기능 보어라 직접 가공이 어려움)
Ø20 무릎 샤프트홀, Ø22 릴리프, Ø37 베어링 시트, Ø12 B샤프트 보어, Ø21 카운터보어, Ø49.95 휠 스피곳 + 웨브, Ø14 부시 보어

## 베드 배치 — Ultimaker S5 (330 × 240 × 300)

축정렬 bounding box 로는 안 들어가지만 **회전시키면 전부 눕혀서 들어갑니다.**
아래 회전은 `print-ready` STL 에 이미 적용되어 있습니다.

| 파트 | 축정렬 bbox | 적용된 회전 | 회전 후 점유 | 여유 | 적층높이 |
|---|---|---|---|---|---|
| Thigh | 257.9 × 247.9 | 166.25° | 291.9 × 201.9 | 38.1 mm | 28.0 mm |
| Shin | 288.5 × 271.3 | 9.75° | 321.3 × 231.3 | **8.7 mm** | 65.0 mm |
| Coupler | 146.4 × 209.5 | 150.28° | 219.5 × 129.4 | 110.5 mm | 16.0 mm |

> **정강이는 사방 4.3 mm 밖에 안 남습니다.** `Build Plate Adhesion = None` (브림/스커트 금지),
> 프라임 블롭 위치 확인. Cura 가 범위초과(회색) 처리하면 정강이만 무릎 위에서 2분할
> (랩조인트 + Ø8 다월 + M4) 하세요.

한 판에 하나씩, 총 6판.

## 슬라이서 설정 (PLA)

```
Layer height        0.2 mm
Wall line count     6        (2.4 mm)
Top/Bottom layers   6        (1.2 mm)
Infill              20 %,  Grid 또는 Cubic
Nozzle              210–215 °C   (층간 접착을 위해 살짝 높게)
Bed                 60 °C
Cooling             50 % (첫 층 제외)  — 과냉각은 층간 접착을 깎습니다
Support             불필요 (눕힘 배치)
Adhesion            None (Shin) / Skirt (그 외)
```

## 왜 눕히나 — 세우면 안 되는 이유

세우면 굽힘 인장응력이 **레이어 경계를 가로질러** 걸립니다. 단면계수 자체는 세움이 유리하지만
(셸이 단면 둘레를 한 바퀴 감싸므로) 재료 허용응력이 절반 이하로 떨어져 결국 손해입니다.

무릎에서 45 mm 지점 실제 단면(0.5 mm 격자 수치적분, Z_solid = 23,690 mm³) 기준 **3G 착지 안전율**:

| 배치 | 벽 | 인필 | Z_eff | SF (3G 착지 32.4 N·m) |
|---|---|---|---|---|
| 눕힘 | 6 | 20 % | 5,646 mm³ | **1.65** |
| 눕힘 | 6 | 40 % | 6,797 mm³ | 1.98 |
| 세움 | 6 | 20 % | 10,039 mm³ | **1.21** |
| 세움 | 4 | 20 % | 8,824 mm³ | 1.06 ← 위험 |
| 세움 | 6 | 40 % | 13,452 mm³ | 1.62 |

세움이 불가피하면 최소 **벽 6줄 + 인필 40 %**, 인필 패턴은 **Grid/Lines 만**
(gyroid 는 층마다 경로가 어긋나 축방향 기둥이 생기지 않음).

전체 표: [`../analysis/results/print-orientation-infill.txt`](../analysis/results/print-orientation-infill.txt)
· 배경: [`../../docs/mechanical/04-print-orientation-infill.md`](../../docs/mechanical/04-print-orientation-infill.md)

## 체결부 주의

M4 / M5 체결부는 **황동 열간삽입 인서트** 사용. PLA 직접 탭은 안전율 0.47 로 나사산이 뽑힙니다.
휠 M6 4개는 **Ø18 대형와셔 + 조임토크 4~6 N·m** 로 제한 (그냥 조이면 PLA가 눌려 예압이 풀립니다).

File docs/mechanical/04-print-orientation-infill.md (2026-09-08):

# 04 — 3D 프린팅 적층 방향 · 인필 · 베드 적재

재현: `hardware/analysis/print_strength.py`
결과 스냅샷: [`print-orientation-infill.txt`](../../hardware/analysis/results/print-orientation-infill.txt)
슬라이서 설정: [`hardware/print/README.md`](../../hardware/print/README.md)

## 0. 결론

1. **세울 필요가 없습니다.** 축정렬 bounding box 로는 Ultimaker S5(330×240)에 안 들어가지만,
   베드 위에서 회전시키면 허벅지·정강이·보조링크 전부 눕혀서 들어갑니다.
2. 세워서 20 % 인필이면 평상시 주행은 견디지만 **3G 착지 안전율이 1.21 로 무너집니다.**
   같은 설정을 눕히면 1.65 — 36 % 더 여유가 있고 파단 모드도 훨씬 안전합니다.
3. **권장: 눕힘 + 벽 6줄(2.4 mm) + 인필 20 %.**

## 1. 임계단면 (Fusion 실측)

바퀴에서 오는 힘을 무릎 핀이 받으므로 최대 굽힘은 무릎 근처입니다.
무릎에서 45 mm 지점을 **0.5 mm 격자로 수치적분한 실제 단면**(경량화 구멍·보스 포함):

| 파트 | 단면적 | 깊이 | c | I | **Z_solid** |
|---|---|---|---|---|---|
| 07/09 Shin | 1,988 mm² | 70 mm | 35.25 mm | 835,084 mm⁴ | **23,690 mm³** |
| 06/08 Thigh | 2,044 mm² | 72 mm | 36.25 mm | 907,664 mm⁴ | **25,039 mm³** |

중앙부는 각각 28,061 / 32,598 mm³ 로 더 크므로 무릎 쪽이 지배합니다.

## 2. 왜 방향이 중요한가

| | 눕힘 (링크면 ‖ 베드) | 세움 (링크면 ⊥ 베드) |
|---|---|---|
| 적층 방향 | 두께 방향 (28 / 65 mm) | **부재 축 방향** |
| 굽힘 인장응력 | 레이어 **안**에서 필라멘트를 따라 | 레이어 **경계를 가로질러** |
| PLA 인장강도 | ~50 MPa | ~28 MPa (56 %) |
| 결함 민감도 | 한 층 불량은 위아래 층이 다리 놓음 | **한 층 불량 = 전폭 균열 시작점** |
| 설계허용응력 | **17 MPa** (SF≈3) | **7 MPa** (SF≈4, 산포 큼) |

세우면 **단면계수는 오히려 유리**합니다 — 셸이 단면 둘레를 한 바퀴 감싸니까요.
하지만 **재료 허용응력이 절반 이하**로 떨어져 결국 손해입니다.

유효 단면계수는 실제 단면 격자를 **벽 두께 t 만큼 침식(erosion)** 시켜 셸/코어를 나누고
`Z_eff = (I_shell + ρ_infill · I_core) / c` 로 계산했습니다.
눕힘은 상하 스킨 0.8 mm 만 솔리드이고 ±45° 인필의 축방향 기여를 0.3ρ 로 잡았습니다.

## 3. 하중 케이스

질량 11.187 kg, 바퀴 반력 54.9 N, 모멘트팔 196.8 mm, Kt = 1.8

| 케이스 | 모멘트 |
|---|---|
| A 정지 균형 | 10.80 N·m |
| B 급가감속 1G (μ=0.8 + 휠토크 반력) | 17.60 N·m |
| C 3G 착지 | 32.39 N·m |

## 4. 안전율 — 07_Shin_L

| 배치 | 벽 | 인필 | Z_eff | Z/Zsolid | SF A | SF B | **SF C** |
|---|---|---|---|---|---|---|---|
| 눕힘 | 3 | 20 % | 3,981 | 17 % | 3.48 | 2.14 | 1.16 |
| 눕힘 | 4 | 20 % | 4,825 | 20 % | 4.22 | 2.59 | 1.41 |
| **눕힘** | **6** | **20 %** | **5,646** | **24 %** | **4.94** | **3.03** | **1.65** |
| 눕힘 | 6 | 40 % | 6,797 | 29 % | 5.95 | 3.65 | 1.98 |
| 눕힘 | 10 | 20 % | 8,688 | 37 % | 7.60 | 4.66 | 2.53 |
| 세움 | 3 | 20 % | 7,538 | 32 % | 2.72 | 1.67 | **0.91** |
| 세움 | 4 | 20 % | 8,824 | 37 % | 3.18 | 1.95 | **1.06** |
| **세움** | **6** | **20 %** | **10,039** | **42 %** | 3.62 | 2.22 | **1.21** |
| 세움 | 6 | 40 % | 13,452 | 57 % | 4.85 | 2.97 | 1.62 |
| 세움 | 10 | 40 % | 16,597 | 70 % | 5.98 | 3.67 | 1.99 |

판정 기준: SF ≥ 2.0 안전 / 1.5–2.0 사용가능 / < 1.5 위험

> 세움 + 벽 3~4줄 + 20 % 는 3G 에서 SF < 1.1 → 실질 파손.
> 세움이 불가피하면 최소 **벽 6줄 + 인필 40 %**(SF 1.62), 실질적으로는 벽 10줄 + 40 %.
> 세움에서 인필은 **grid/lines 만 유효** — gyroid 는 층마다 경로가 어긋나 축방향 기둥이 생기지 않습니다.

## 5. 베드 적재 (Ultimaker S5 330 × 240 × 300)

실제 외곽선 convex hull 을 0.025° 단위로 회전 스캔한 결과:

| 파트 | 축정렬 bbox | 최적 회전 | 회전 후 점유 | 여유 | 적층높이 |
|---|---|---|---|---|---|
| 06/08 Thigh | 257.9 × 247.9 | **166.25°** | 291.9 × 201.9 | 38.1 mm | 28.0 mm |
| 07/09 Shin | 288.5 × 271.3 | **9.75°** | 321.3 × 231.3 | **8.7 mm** | 65.0 mm |
| 02/03 Coupler | 146.4 × 209.5 | **150.28°** | 219.5 × 129.4 | 110.5 mm | 16.0 mm |

정강이는 사방 4.3 mm 만 남으므로 **브림/스커트를 끄고(Adhesion = None)** 프라임 블롭 위치를
확인해야 합니다. Cura 가 범위초과 처리하면 정강이만 무릎 위에서 2분할
(랩조인트 + Ø8 다월 + M4)하세요.

이 회전은 `hardware/print/print-ready/*_PRINT.stl` 에 이미 적용되어 있고,
원본 대비 체적 오차 **0.0000 %**, Z_min = 0 을 검증했습니다.

## 6. 세워 출력의 비-강도 문제

정강이를 세우면 288.5 mm 높이 × 좁은 바닥면 → 0.2 mm 레이어로 **1,443 층**,
링잉·전도 위험, 서포트 대량 발생, 20 시간 이상 출력 중 마지막에 실패하면 전부 손실입니다.
또 휠 체결 플랜지(4-M6)가 바닥 쪽에 오면서 볼트 하중이 층간 방향으로 걸립니다.

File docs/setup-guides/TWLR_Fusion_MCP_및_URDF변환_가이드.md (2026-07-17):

# TWLR — Fusion 360 MCP 연결 & URDF 변환 가이드

> 작성 목적: 다른 팀원도 처음부터 동일하게 재현할 수 있도록, 두 작업 세션(① Claude Desktop ↔ Fusion 360 MCP 연결, ② Fusion 모델 → URDF 변환 → RViz2/Gazebo 실행)을 단계별로 정리한 문서.
>
> 환경: Windows(작업 PC) + Fusion 360(교육용 라이선스) / Ubuntu 24.04 + ROS2 Jazzy + Gazebo Harmonic(gz sim 8.11.0)

---

## PART 1. Claude Desktop ↔ Fusion 360 MCP 연결 설정

### 1-1. 배경 및 핵심 문제

- 목표: Claude가 Fusion 360 디자인을 직접 읽고 조작할 수 있도록 MCP로 연결.
- **교육용(학생) 라이선스의 Fusion 360에는 공식 MCP 서버 옵션이 없음** (환경설정 → 일반에 API 섹션이 아예 안 뜸).
- 해결책: 서드파티 애드인 **`frankhommers/autodesk-fusion-mcp`** (GitHub) 사용.

### 1-2. 사전 준비

1. **Node.js 설치** — `npx` 명령이 필요하므로 미설치 시 먼저 설치.
2. Fusion 360 실행 상태 유지.
3. **Claude Desktop 앱** 사용 (⚠️ 웹 브라우저 버전 Claude에서는 로컬 MCP 도구가 작동하지 않음).

### 1-3. Fusion 애드인 설치

1. GitHub에서 `frankhommers/autodesk-fusion-mcp` zip 다운로드 후 압축 해제.
2. **폴더명/구조 주의 (가장 흔한 실수)**
   - 압축 해제 시 `autodesk-fusion-mcp-main` 폴더가 생기는데, 이 폴더를 **정확히 `AutodeskFusionMCP`로 이름 변경**해야 함.
   - 설치 위치: `%APPDATA%\Autodesk\Autodesk Fusion 360\API\AddIns\`
   - 이중 중첩 금지: `AddIns\AutodeskFusionMCP\AutodeskFusionMCP\파일들` 구조면 Fusion이 인식 못 함.
   - 올바른 구조: `AddIns\AutodeskFusionMCP\(실제 파일들)`
3. Fusion에서 **Shift + S** → Add-ins 탭 → `AutodeskFusionMCP` 활성화(파란색 토글 = 켜짐).

### 1-4. Claude Desktop 설정 파일 수정

- 파일 위치: `C:\Users\<사용자명>\AppData\Roaming\Claude\claude_desktop_config.json`
- VS Code 등으로 열어 최상위에 `mcpServers` 키 추가 (기존 키들은 그대로 두고 추가만 하면 됨):

```json
"mcpServers": {
  "autodesk-fusion-mcp": {
    "command": "npx",
    "args": [
      "mcp-remote",
      "http://127.0.0.1:8765/mcp"
    ]
  }
}
```

- ⚠️ `"type": "http"` + `"url"` 형식은 Claude Desktop이 **유효하지 않은 설정으로 거부**함. 반드시 위처럼 `npx mcp-remote` 방식 사용.

### 1-5. 적용 및 확인

1. Claude Desktop **완전 종료 필수**: 작업표시줄 우측 숨겨진 아이콘(^) → Claude 아이콘 우클릭 → 종료 → 재실행. (창만 닫으면 설정이 반영 안 됨)
2. 설정(톱니바퀴) → 개발자 → 로컬 MCP 서버 목록에서 `autodesk-fusion-mcp`가 **running** 상태인지 확인.
3. 포트 확인(선택): cmd에서 `netstat -ano | findstr :8765` → `LISTENING`/`ESTABLISHED` 표시되면 서버 정상.
4. Claude Desktop **새 채팅**에서 "Fusion에서 현재 열려있는 디자인 이름이 뭐야?"로 테스트.

### 1-6. 트러블슈팅 체크리스트

| 증상 | 원인 / 조치 |
|---|---|
| MCP 서버 목록에 항목이 안 뜸 | config 저장 확인 → Claude Desktop 트레이에서 완전 종료 후 재시작 |
| running인데 도구 호출 실패 | 웹 브라우저 버전에서 시도 중인지 확인 → Desktop 앱에서만 동작 |
| Fusion이 애드인을 인식 못 함 | 폴더명 `AutodeskFusionMCP` 정확히 일치 + 이중 중첩 여부 확인 |
| 연결 자체가 안 됨 | Node.js 설치 여부, Fusion 실행 여부, 포트 8765 점유 확인 |

---

## PART 2. Fusion 360 TWLR 모델 → URDF 변환 → RViz2/Gazebo 실행

### 2-1. 모델 개요

- 디자인 이름: **TWLR** (Two-Wheeled Legged Robot)
- 구조: 좌/우 다리 × (link1 허벅지, link2 4절링크 보조링크, link3 정강이) + 인휠모터, 4절 링크(4-bar linkage) 다리 구조
- torso에 전자부품: Teensy 4.1, Orange Pi, IMU, 1000mAh LiPo 배터리, PDB, ODrive V3.6 모터드라이버, FeeTech SM60CL 서보 ×2
- 목표: MuJoCo/Gazebo용 URDF 생성 (전자부품 포함 버전 A / 제외 버전 B 두 가지)

### 2-2. Fusion 쪽 조인트 세팅 (MCP `execute_python` 활용)

최종적으로 **As-Built Joint 18개** 구성:

**회전 관절 (Revolute) — 10개**

| Joint | 연결 | 축 |
|---|---|---|
| `hip_right` / `hip_left` | torso ↔ link1 | X |
| `aux_hip_right` / `aux_hip_left` | torso ↔ link2 | X (4-bar 상단) |
| `knee_right` / `knee_left` | link1 ↔ link3 | X |
| `link2_link3_right` / `link2_link3_left` | link2 ↔ link3 | X (4-bar 하단) |
| `wheel_right` / `wheel_left` | link3 ↔ 인휠모터 | Y (바퀴 회전) |

**고정 관절 (Rigid) — 8개**: 서보 ×2 + 전자부품 6종 → torso에 고정.
단, 전자부품은 rigid joint보다 **Rigid Group**(`torso_electronics`)으로 묶는 것이 fusion2urdf 인식률이 좋음 → torso + 전자부품 전체를 하나의 URDF 링크로 병합됨.

**Fusion API 팁 (조인트 자동 생성 시):**
- 조인트 기준점은 `JointGeometry.createByCylinderOrConeFace(face, ...)` 사용. `createByPoint`는 `Point3D`를 받지 않음(실제 BRep 지오메트리 필요).
- 원통면(핀 홀) 탐지는 반지름 오차(±0.15) + 축 방향 내적 조건을 함께 걸어야 안정적.
- 공유 컴포넌트의 월드 좌표는 로컬 origin에 transform translation을 더해 계산하되, **미러된 컴포넌트는 origin 계산이 불안정**하므로 face 인덱스 직접 접근이 안전.

### 2-3. fusion2urdf 규칙 및 주요 함정 ★핵심★

1. **As-Built Joint 방향**: `occurrenceOne = child`, `occurrenceTwo = parent` (직관과 반대!). 방향이 틀리면 kinematic tree가 뒤집혀 base_link가 leaf로 잡힘.
2. **공유 컴포넌트 문제**: 같은 컴포넌트를 좌/우 다리에 인스턴스로 재사용하면 fusion2urdf가 하나의 링크로 병합해버림 → `body.copyToComponent()`로 **독립 컴포넌트로 분리**해야 좌/우가 각각 링크로 나옴.
3. **Orphan link 오류**: kinematic tree에 연결 안 된 컴포넌트가 있으면 export 실패 → 모든 컴포넌트가 joint 또는 Rigid Group으로 tree에 연결됐는지 확인.
4. **4절 링크의 폐루프(closing loop)**: 조인트 이름에 `!closing_` 접두사를 붙여 명시적으로 표시.
5. **인코딩 버그**: `fusion2urdf/core/package_generator.py` 약 879행의 파일 open에 `encoding='utf-8'` 추가 필요 (한글 경로/이름에서 크래시).
6. **디버깅 방법**: debug 폴더의 `export_log.md`와 `snapshot.json` 확인. `snapshot.json`의 `joints[이름].occurrence_one_clean` / `occurrence_two_clean` 필드로 parent/child 해석 결과를 정확히 볼 수 있음.

### 2-4. Export 절차

1. fusion2urdf 애드인 실행: Utilities → Add-Ins → Scripts and Add-Ins → `fusion2urdf`
2. **버전 A (전자부품 포함)**: 현재 상태 그대로 export.
3. **버전 B (전자부품 제외)**: 브라우저에서 `Teensy_4.1:1`, `Orange pi:1`, `IMU sensor:1`, `1000mah LIPO battery:1`, `DIANOME PDB (1):1`, `Motor driver ODRIVE V3.6:1` 우클릭 → Suppress → export → 다시 Unsuppress.
4. Export 전 Fusion 저장 권장.

### 2-5. Ubuntu 측 빌드 및 실행

1. USB 등으로 export 산출물(ROS2 패키지, 예: `TWLR_description`)을 Ubuntu로 이동.
2. `~/ros2_ws/src`에 넣고 `colcon build` → `source install/setup.bash`.
3. **RViz2**: `robot_state_publisher` + `joint_state_publisher_gui` 런치로 확인.
4. **Gazebo Harmonic 주의사항**:
   - 링크 이름과 조인트 이름이 같은 문자열이면 충돌 → sed로 조인트 이름 수정 (예: `wheel_right` → `wheel_right_joint`).
   - 메시 경로 해석을 위해 환경변수 설정 필수:
     ```bash
     export GZ_SIM_RESOURCE_PATH=$HOME/ros2_ws/install/TWLR_description/share
     ```
   - `/tmp/TWLR.urdf` 작업 파일은 재부팅 시 사라짐 → xacro 변환 + sed 수정을 다시 실행해서 재생성해야 함.

### 2-6. 남은 이슈 (다음 작업자 참고)

- **왼쪽 다리 표시 오류**: `hip_left` 조인트가 임시방편으로 `link1_right`에 부모 연결된 상태 → URDF에서 부모를 torso로 수동 수정 필요.
- 일부 joint origin 값이 부정확 → URDF에서 수동 보정 필요.
- 서보(`servo_right`/`servo_left`)는 현재 rigid → 실제로는 link3 구동이므로 필요 시 revolute로 재정의.

---

---

## PART 3. Gazebo / MuJoCo에서 부품 수치·위치 수정하기

결론: 가능함. 다만 "어디서" 수정하느냐에 따라 방식이 다름 — Gazebo는 URDF를 직접 수정, MuJoCo는 MJCF(XML)를 직접 수정.

### 3-1. Gazebo (SDF/URDF 쪽)

Gazebo는 URDF(또는 변환된 SDF)를 그대로 읽어서 쓰기 때문에, URDF 파일 자체를 직접 수정하면 됨.

- **위치/자세**: 각 `<joint>`의 `origin xyz="x y z" rpy="r p y"` 값을 수정하면 링크 간 상대 위치가 바뀜. `hip_left` 부모 연결 문제나 joint origin 부정확 문제도 이렇게 손으로 고치면 됨.
- **질량/관성**: 각 `<link>`의 `<inertial>` 블록 (`mass value="..."`, `inertia ixx="..."` 등) 수정.
- **충돌/시각 형상 크기**: `<collision>`, `<visual>` 안의 geometry (box size, cylinder radius/length 등).
- 수정 후엔 다시 `colcon build` (xacro 쓰는 경우 재변환) → sed로 이름 충돌 재수정 → Gazebo 재실행 필요. `/tmp/TWLR.urdf`처럼 재부팅 시 사라지는 임시 파일이면 매번 재생성해야 함.

### 3-2. MuJoCo (MJCF 쪽)

손으로 만든 MJCF 모델(2족+2바퀴, 8 액추에이터)도 같은 방식으로 XML을 직접 편집하면 됨.

- **위치**: 각 `<body>` 태그의 `pos="x y z"`, `quat` 또는 `euler` 속성.
- **질량/관성**: `<inertial>` 태그의 `mass`, `diaginertia` (또는 `fullinertia`).
- **관절 특성**: `<joint>`의 `range`(가동범위), `damping`, `stiffness`, `armature` 등.
- **액추에이터 게인**: `<actuator>` 블록의 `gear`, `kp`, `forcerange` 등 — 밸런스 컨트롤러 튜닝할 때 특히 중요.
- 편집 후 `mujoco.viewer`로 다시 열면 바로 반영됨 (재컴파일 불필요, XML만 다시 로드).

### 3-3. 주의할 점

- **평형 피치각(4.53°)**: 질량 분포(배터리 위치 등)를 바꾸면 이 값도 달라지므로, 부품 위치를 수정했다면 `balance_test.py` 같은 스크립트로 새 평형점을 다시 찾아 컨트롤러 setpoint를 갱신해야 함.
- **URDF→MJCF 변환 경로를 쓰는 경우**: URDF에서 수정 → 다시 변환 순서를 지켜야 두 모델이 어긋나지 않음. MJCF에서만 고치면 다음 변환 때 덮어써짐.
- **파라미터화**(YAML+Jinja2 또는 PyMJCF)를 아직 안 넣었다면, 자주 바꿀 값들(질량, 위치 등)은 그 방식으로 옮겨두면 손 편집보다 훨씬 편해짐.

---

## 전체 파이프라인 요약 (한눈에)

```
[Windows]
 Node.js 설치
   → frankhommers/autodesk-fusion-mcp 애드인 설치 (폴더명 AutodeskFusionMCP)
   → claude_desktop_config.json에 npx mcp-remote 설정
   → Claude Desktop 완전 재시작 → running 확인
   → Claude로 Fusion 조인트 자동 세팅 (As-Built Joint 18개 + Rigid Group)
   → fusion2urdf export (인코딩 패치 적용, occurrenceOne=child 규칙 준수)

[Ubuntu 24.04 + ROS2 Jazzy]
 패키지 이동 → colcon build
   → RViz2 확인
   → sed로 이름 충돌 수정 + GZ_SIM_RESOURCE_PATH 설정
   → Gazebo Harmonic 실행
```

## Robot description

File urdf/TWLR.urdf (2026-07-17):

<?xml version="1.0"?>
<robot name="TWLR">

  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

  <link name="base_link">
    <inertial>
      <origin xyz="-0.009947 0.139666 0.083952" rpy="0 0 0"/>
      <mass value="46.804719"/>
      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
    </inertial>
    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
  </link>

  <link name="link1_right">
    <inertial>
      <origin xyz="0.000000 0.081855 -0.058806" rpy="0 0 0"/>
      <mass value="0.668075"/>
      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
    </inertial>
    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
  </link>

  <link name="link3_right">
    <inertial>
      <origin xyz="-0.020000 -0.091241 -0.155189" rpy="0 0 0"/>
      <mass value="0.808579"/>
      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
    </inertial>
    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
  </link>

  <link name="link1_left">
    <inertial>
      <origin xyz="0.000000 0.078161 -0.063634" rpy="0 0 0"/>
      <mass value="0.668075"/>
      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
    </inertial>
    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
  </link>

  <link name="wheel_right">
    <inertial>
      <origin xyz="0.023768 0.026564 0.007725" rpy="0 0 0"/>
      <mass value="6.891403"/>
      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
    </inertial>
    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
  </link>

  <link name="link3_left">
    <inertial>
      <origin xyz="-0.020000 -0.079980 0.161282" rpy="0 0 0"/>
      <mass value="0.808579"/>
      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
    </inertial>
    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
  </link>

  <link name="wheel_left">
    <inertial>
      <origin xyz="0.023768 0.026564 -0.007725" rpy="0 0 0"/>
      <mass value="6.891403"/>
      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
    </inertial>
    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
  </link>

  <joint name="hip_right" type="continuous">
    <parent link="base_link"/>
    <child link="link1_right"/>
    <origin xyz="0.123370 -0.038877 0.160846" rpy="-0.619267 -0.000000 0.000000"/>
    <axis xyz="1.000000 0.000000 0.000000"/>
    <limit effort="100.0" velocity="1.00"/>
  </joint>

  <joint name="knee_right" type="continuous">
    <parent link="link1_right"/>
    <child link="link3_right"/>
    <origin xyz="0.000000 0.163205 -0.117321" rpy="-2.089403 -0.000000 0.000000"/>
    <axis xyz="1.000000 0.000000 0.000000"/>
    <limit effort="100.0" velocity="1.00"/>
  </joint>

  <joint name="hip_left" type="continuous">
    <parent link="link1_right"/>
    <child link="link1_left"/>
    <origin xyz="0.000000 0.000000 -0.000000" rpy="0.060327 -0.000000 0.000000"/>
    <axis xyz="1.000000 0.000000 0.000000"/>
    <limit effort="100.0" velocity="1.00"/>
  </joint>

  <joint name="wheel_right" type="continuous">
    <parent link="link3_right"/>
    <child link="wheel_right"/>
    <origin xyz="0.039494 -0.006035 0.007648" rpy="-3.141593 0.991862 1.570796"/>
    <axis xyz="0.309017 -0.000000 -0.951057"/>
    <limit effort="100.0" velocity="1.00"/>
  </joint>

  <joint name="knee_left" type="continuous">
    <parent link="link1_left"/>
    <child link="link3_left"/>
    <origin xyz="0.000000 0.155835 -0.126947" rpy="0.000000 -0.000000 0.000000"/>
    <axis xyz="1.000000 0.000000 0.000000"/>
    <limit effort="100.0" velocity="1.00"/>
  </joint>

  <joint name="wheel_left" type="continuous">
    <parent link="link3_left"/>
    <child link="wheel_left"/>
    <origin xyz="-0.303192 0.024704 -0.014133" rpy="3.141593 -0.000000 -1.570796"/>
    <axis xyz="-0.309017 0.000000 -0.951057"/>
    <limit effort="100.0" velocity="1.00"/>
  </joint>

  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
  <ros2_control name="TWLR_system" type="system">
    <hardware>
      <plugin>mock_components/GenericSystem</plugin>
      <param name="cmd_topic">sim/TWLR_system/cmd</param>
      <param name="state_topic">sim/TWLR_system/state</param>
    </hardware>

    <joint name="hip_left">
      <command_interface name="position"/>
      <command_interface name="velocity"/>
      <state_interface name="position">
        <param name="initial_value">0.0</param>
      </state_interface>
      <state_interface name="velocity"/>
      <state_interface name="effort"/>
    </joint>
    <joint name="hip_right">
      <command_interface name="position"/>
      <command_interface name="velocity"/>
      <state_interface name="position">
        <param name="initial_value">0.0</param>
      </state_interface>
      <state_interface name="velocity"/>
      <state_interface name="effort"/>
    </joint>
    <joint name="knee_left">
      <command_interface name="position"/>
      <command_interface name="velocity"/>
      <state_interface name="position">
        <param name="initial_value">0.0</param>
      </state_interface>
      <state_interface name="velocity"/>
      <state_interface name="effort"/>
    </joint>
    <joint name="knee_right">
      <command_interface name="position"/>
      <command_interface name="velocity"/>
      <state_interface name="position">
        <param name="initial_value">0.0</param>
      </state_interface>
      <state_interface name="velocity"/>
      <state_interface name="effort"/>
    </joint>
    <joint name="wheel_left">
      <command_interface name="position"/>
      <command_interface name="velocity"/>
      <state_interface name="position">
        <param name="initial_value">0.0</param>
      </state_interface>
      <state_interface name="velocity"/>
      <state_interface name="effort"/>
    </joint>
    <joint name="wheel_right">
      <command_interface name="position"/>
      <command_interface name="velocity"/>
      <state_interface name="position">
        <param name="initial_value">0.0</param>
      </state_interface>
      <state_interface name="velocity"/>
      <state_interface name="effort"/>
    </joint>
  </ros2_control>

</robot>

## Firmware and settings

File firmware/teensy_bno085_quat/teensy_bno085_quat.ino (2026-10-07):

#include <Adafruit_BNO08x.h>

Adafruit_BNO08x bno08x;
sh2_SensorValue_t sensorValue;

void setup() {
  Serial.begin(115200);
  while (!Serial) delay(10);
  
  // BNO085 I2C 초기화
  if (!bno08x.begin_I2C()) {
    while (1) { delay(10); }
  }
  // 게임 회전 벡터(Game Rotation Vector) 리포트 활성화
  bno08x.enableReport(SH2_GAME_ROTATION_VECTOR);
}

void loop() {
  if (bno08x.getSensorEvent(&sensorValue)) {
    if (sensorValue.sensorId == SH2_GAME_ROTATION_VECTOR) {
      // 쿼터니언 데이터(i, j, k, real)를 CSV 형태로 시리얼 출력
      Serial.print(sensorValue.un.gameRotationVector.i, 4);
      Serial.print(",");
      Serial.print(sensorValue.un.gameRotationVector.j, 4);
      Serial.print(",");
      Serial.print(sensorValue.un.gameRotationVector.k, 4);
      Serial.print(",");
      Serial.println(sensorValue.un.gameRotationVector.real, 4);
    }
  }
  delay(10);
}

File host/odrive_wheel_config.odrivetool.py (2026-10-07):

# ODrive 휠모터(WA172E) 초기 설정 — odrivetool 셸에 붙여넣어 실행 (3주차 발표 슬라이드 19)
# LattePanda 에서 휠 구동 테스트에 사용. 게인은 시작값이며 이후 튜닝.

# 모터
odrv0.axis0.motor.config.pole_pairs = 15
odrv0.axis0.motor.config.torque_constant = 1
odrv0.axis0.motor.config.calibration_current = 5
odrv0.axis0.motor.config.resistance_calib_max_voltage = 8
odrv0.axis0.motor.config.current_lim = 10

# 엔코더 (J3: A, B)
odrv0.axis0.encoder.config.mode = ENCODER_MODE_INCREMENTAL
odrv0.axis0.encoder.config.cpr = 3200
odrv0.axis0.encoder.config.use_index = False
odrv0.axis0.config.startup_encoder_index_search = False

# 제어 (시작값, 이후 튜닝)
odrv0.axis0.controller.config.vel_limit = 3
odrv0.axis0.controller.config.pos_gain = 20
odrv0.axis0.controller.config.vel_gain = 0.5
odrv0.axis0.controller.config.vel_integrator_gain = 1

odrv0.save_configuration()
odrv0.reboot()

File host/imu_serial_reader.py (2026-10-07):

"""BNO085 쿼터니언 수신·파싱 (Ubuntu 호스트 / LattePanda) — Teensy 4.1 USB 시리얼 CSV "i,j,k,real".
   3주차 발표 슬라이드 22 코드 그대로. 사용: pip install pyserial && python3 imu_serial_reader.py
"""
import serial
import sys
import time

# 우분투 환경에 맞는 시리얼 포트 설정
SERIAL_PORT = '/dev/ttyACM0'  # 필요시 ttyACM1로 변경
BAUD_RATE = 115200

def main():
    print(f"Connecting to {SERIAL_PORT} at {BAUD_RATE} baud...")
    try:
        ser = serial.Serial(SERIAL_PORT, BAUD_RATE, timeout=1)
        time.sleep(2) # 연결 안정화 대기
    except Exception as e:
        print(f"Failed to connect to serial port: {e}")
        sys.exit(1)

    print("Listening for BNO085 IMU data... Press Ctrl+C to exit.")
    
    try:
        while True:
            if ser.in_waiting > 0:
                line = ser.readline().decode('utf-8', errors='ignore').strip()
                if line:
                    # 쉼표(,)로 데이터 분리
                    parts = line.split(',')
                    if len(parts) == 4:
                        try:
                            qx = float(parts[0])
                            qy = float(parts[1])
                            qz = float(parts[2])
                            qw = float(parts[3])
                            
                            # 수신된 쿼터니언 데이터 출력 (제어 알고리즘 및 ROS 2 연동 지점)
                            print(f"Quaternion -> X: {qx:.3f}, Y: {qy:.3f}, Z: {qz:.3f}, W: {qw:.3f}")
                        except ValueError:
                            pass
    except KeyboardInterrupt:
        print("\nExiting program...")
    finally:
        ser.close()

if __name__ == '__main__':
    main()

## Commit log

2026-07-17 Initial commit: TWLR_description ROS2 package + Fusion MCP/URDF setup guide
    - URDF, xacro, meshes, launch, config for TWLR (Two-Wheeled Legged Robot)
    - docs/setup-guides: Fusion 360 MCP connection + URDF conversion + Gazebo/MuJoCo editing guide (md + docx)
    [TWLR.urdf, TWLR.urdf.xacro, base_link_collision.stl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]
2026-09-08 기구 설계 현행화: AK45-36 고관절 + WA172E 체결 + 조인트/프린팅 문서화
    TWLR_assembly_AK45 (컴포넌트 31 / 오컬런스 55 / 타임라인 281) 기준으로
    기구 설계 일체를 hardware/ 아래에 정리했다.
    추가한 것
    - hardware/cad: Fusion 원본 f3d, 신규 가공품 STEP 5종
    (출력 허브, AK45 마운트링, A/KNEE/B 샤프트)
    - hardware/print: print-ready STL 6종(구멍 제거 + 눕힘 + 베드 최적 회전 + Z=0,
    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
    [02_Coupler_L.stl, 02_Coupler_L_PRINT.stl, 03_Coupler_R.stl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]
2026-09-08 발표자료(2026-2 week1)와 어셈블리 애니메이션 추가
    원본 pptx 는 101 MB 라 커밋하지 않고 슬라이드 12장(PNG) + PDF + 영상 8편으로
    분해해 넣었다. 영상은 전부 H.264 로 재인코딩 (원본 .mov 는 HEVC 라 브라우저 재생 불가),
    92 MB -> 20 MB.
    - hardware/media/assembly-animation.mp4 어셈블리 애니메이션 27 s
    - docs/presentations/2026-2-week1/
    2026-2-week1.pdf 전체 슬라이드
    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
2026-09-08 Assembly Breakdown: Fusion 실측 물성치로 갱신
2026-09-08 Update CAD tools listed in README
2026-10-07 고관절 DM4340P 교체 반영 + 2·3주차 발표자료·영상·BOM 추가
    - 고관절 액추에이터 CubeMars AK45-36 → Damiao DM-J4340P-2EC (AK45 배송 지연)
    - docs/mechanical/05-hip-actuator-DM4340P.md 신규: 사양 비교, 토크 재계산, 팀 정역학과의 차이, CAD 수정 필요 사항
    - 해석 스크립트에 TWLR_ACT 선택 추가 (기본 DM4340P, AK45 재현 가능), 하드코딩 경로 제거
    - sweep_infill.py 인필 치환이 동작하지 않던 문제 수정
    - 결과: 총질량 11.239 kg, 직립 9.59 N·m (정격 9 의 107 %), 연속 한계 Δθ ≤ -5.5°
    - 기존 AK45 결과는 results/*_AK45.txt 로 보존, 01/02/03 문서에 변경 안내
    - hardware/b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
    [TWLR_BOM.xlsx]
2026-10-07 2·3주차 발표 영상 추가 (H.264 재인코딩)
    Claude-Session: https://claude.ai/code/session_01GfbbUqeW5t1CKgxxuPdG14
2026-10-07 README 상단에 모션 쇼케이스·어셈블리 GIF 미리보기 배치
    GitHub README 는 저장소 내 mp4 를 인라인 재생하지 않으므로 GIF(1.5~2배속) 미리보기를
    두고 클릭 시 원본 mp4 로 연결.
    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
2026-10-11 docs: README 재구성(접기·핵심 결과·읽는 순서), 대화체 문구 정리, 구버전 가이드 경고 추가
    Claude-Session: https://claude.ai/code/session_01RLbmtTaxr7w6t9e19UBunk
2026-10-11 docs: 2학기 통합본 발표 반영 — CAN 통합 계획 · 제어 원리 · 운용 방법
    - docs/presentations/2026-2-integrated: 110장 슬라이드 이미지 · PDF · 신규 IMU RPY 영상
    - docs/electronics: 01 CAN 통합 구동 계획, 02 코드 해설 · 원리, 03 운용 방법
    - host: ODrive 2축 CAN 설정 스크립트, DM4340P 1회 설정 가이드
    - README · hardware · BOM · firmware · host · 주차별 발표 README 갱신
    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
2026-10-13 feat(sim): Gazebo Harmonic 균형 시뮬레이션 패키지 · 검증 결과 · 문서 추가
    - sim/twlr_description: CATIA 기반 새 URDF(9.62 kg), 월드, gz 브리지, 런치
    - sim/twlr_control: 1단계 균형 제어기(속도 PI → pitch PD, yaw PI)
    - sim/verify: Gazebo 없이 URDF·메시·제어기를 검증하는 재현 스크립트와 결과
    - docs/simulation: 구성·실행·값, 검증 결과, CAD(11.24 kg)와의 차이, 열린 항목
    - README / hardware README: 시뮬레이션 섹션 추가, URDF 질량 경고 갱신
    실제 Gazebo 구동은 미확인 (검증은 계산 + 평면 바퀴-역진자 모델).
    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
2026-11-01 docs: 고관절 받침·클램프 체결 실물 반영, 외형 치수 추가
    - README 기구 설계 요약에 고관절 체결(받침 x2, 반쪽 클램프 x4) · 외형 치수 행 추가
    - hardware/README 미해결 3번에 하우징 고정 진행 상황 기록
    Claude-Session: https://claude.ai/code/session_01XswzVtjBA8oFvuMznCCpYJ
